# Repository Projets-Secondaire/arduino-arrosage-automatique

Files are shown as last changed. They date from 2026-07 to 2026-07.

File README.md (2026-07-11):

# Arrosage automatique (SI4) – Arduino

Situation d'intégration 4 – Projet de fin d'étude, qualification Électricien-Automaticien
Institut Saint Joseph, Etterbeek – Année académique 2023-2024

## Description

Système d'arrosage automatique pour les plantes de l'atelier, développé sur Arduino UNO. Le système gère à la fois le remplissage d'un réservoir d'eau (depuis un aquarium) et l'irrigation goutte-à-goutte des plantes, avec un sélecteur permettant de basculer entre un mode manuel et un mode automatique piloté par capteurs d'humidité.

## Fonctionnement

**Mode manuel**
- Maintien du bouton de remplissage → la pompe de l'aquarium remplit le réservoir
- Maintien du bouton d'arrosage → la pompe du réservoir démarre et les deux électrovannes s'ouvrent

**Mode automatique**
- Si les deux capteurs d'humidité du sol détectent une sécheresse → la pompe du réservoir démarre et les électrovannes s'ouvrent automatiquement
- Le remplissage du réservoir est régulé par un capteur à ultrason (niveau bas / niveau haut)

**Sécurité**
- Bouton d'arrêt d'urgence (coup de poing) + bouton de reset dédié
- 4 témoins de signalisation : arrosage en cours (vert), niveau bas (jaune), niveau haut (bleu), arrêt d'urgence (rouge clignotant)

## Matériel principal

- Arduino UNO R3
- 2 capteurs d'humidité du sol (hygromètre LM393)
- 1 capteur à ultrason (niveau du réservoir)
- 2 pompes submersibles d'aquarium (JEBAO JECOD)
- 2 électrovannes
- Module 8 relais
- Sélecteur manuel/automatique, boutons poussoir, arrêt d'urgence + reset
- 4 témoins LED de signalisation

La liste complète du matériel (références, caractéristiques techniques, justification des choix) est disponible dans le rapport.

## Firmware

- `firmware/arrosage_automatique/` : programme principal (gestion des deux modes, sécurité, lecture des capteurs)
- `firmware/test_seuil_humidite/` : test isolé du capteur d'humidité du sol, utilisé pour calibrer le seuil avant intégration au programme final

## Rapport complet

Le rapport complet (cahier des charges, étude du système, choix technologiques, dimensionnement, schémas, liste du matériel, grafcet niveau 1/2/3, conclusions et maintenance) est disponible dans [`docs/rapport_arrosage_automatique.pdf`](docs/rapport_arrosage_automatique.pdf).

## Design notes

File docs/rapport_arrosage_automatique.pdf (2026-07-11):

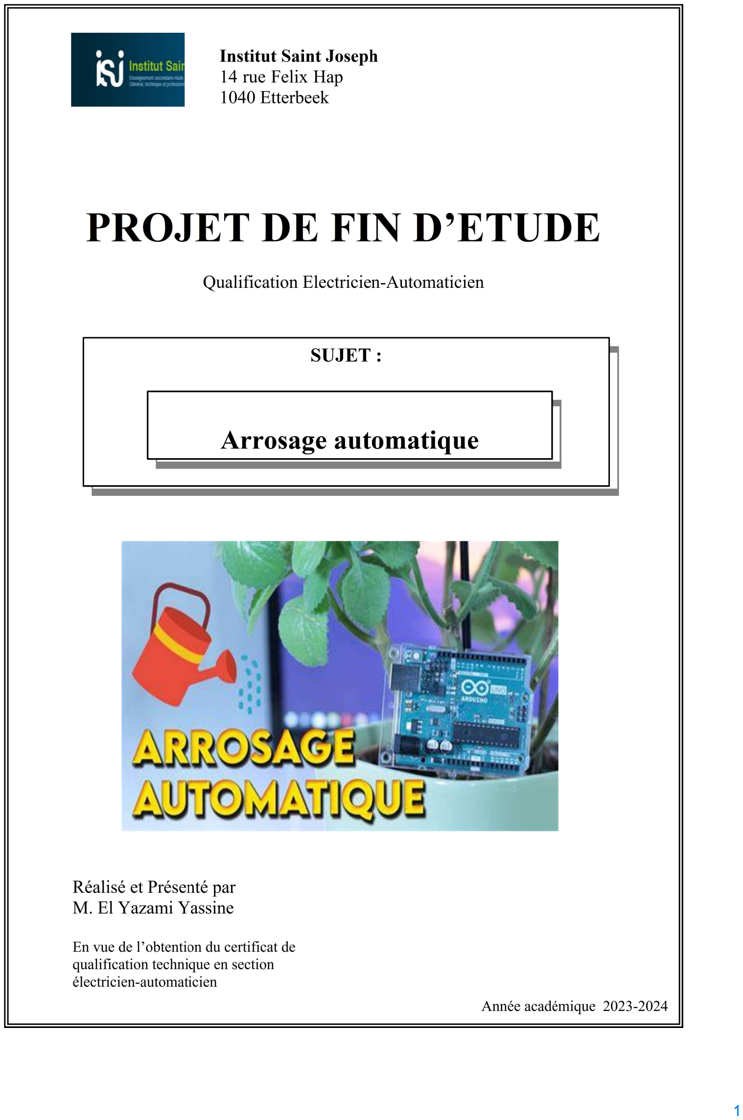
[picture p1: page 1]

## Table des matières

Généralités

But de ce travail de fin d’étude

Ce travail de fin d’étude fait partie de la situation intégrée n°4. Combiné avec trois autres situations intégrées et l'évaluation du stage, permettront d’obtenir le certificat de qualification.
Mes accompagnateurs sont

Monsieur Duliere Bruno qui a joué le rôle de Maître de projet et qui a vérifié le contenu du rapport d’un point de vue technique.
Monsieur Fouad m'a beaucoup aidé avec l'Arduino. Il a pris le temps de m'expliquer comment ça marche et a même corrigé des erreurs dans mon programme. Grâce à lui, j'ai beaucoup mieux compris comment utiliser cette technologie pour mon projet. Madame Bouhamam Kheira m'a aussi apporté une aide précieuse, surtout pour les maths.

Je suis vraiment reconnaissant pour toute l'aide qu'ils m'ont donnée. Ils ont rendu mon travail sur ce projet beaucoup plus facile et agréable

Mes souhait

Dans le cadre du développement de mon projet d'arrosage autonome, mes attentes sont précises et s'articulent autour de la nécessité de maintenir une irrigation efficace et autonome des plantes de l'atelier 200, surtout pendant les périodes où une intervention humaine régulière n'est pas possible.

Le but principal de ce système est de garantir que ces plantes reçoivent la quantité d'eau nécessaire à leur santé et croissance, sans que cela nécessite une intervention manuelle. Cela est particulièrement crucial durant les mois d'été, tels que juillet et août, lorsque les températures élevées peuvent rapidement assécher le sol et où la disponibilité humaine pour l'arrosage peut être limitée.

Je souhaite donc mettre en place un système d'arrosage géré par des capteurs qui détectent l'humidité du sol. Ces capteurs auront pour fonction d'analyser en continu l'état d'humidité et de déclencher un système d'arrosage automatique lorsque le niveau d'humidité descend en dessous d'un seuil prédéfini. Ce mécanisme doit permettre une distribution d'eau homogène et adaptée aux besoins spécifiques de chaque plante.

L'intégration de la technologie Arduino, avec ses capteurs d'humidité du sol, est au cœur de mon projet. Ce choix technologique offre une flexibilité et une précision essentielles pour le contrôle automatisé du système d'arrosage.

En outre, je m'attends à ce que ce système soit économique en eau, contribuant ainsi à une gestion environnementale responsable. Il devrait également être robuste et durable, capable de fonctionner de manière autonome avec un minimum de maintenance.

Mes objectifs

Mon projet d'arrosage autonome représente non seulement une solution pratique pour assurer l'hydratation adéquate des plantes durant les périodes d'absence ou les mois les plus chauds, mais il s'agit également d'une excellente opportunité pour étendre mes compétences techniques et explorer des innovations dans le domaine de l'irrigation.

Approfondissement des compétences techniques: L'utilisation de la plateforme Arduino pour contrôler les capteurs d'humidité du sol et gérer l'irrigation me permettra de parfaire mes connaissances en électronique et en programmation.

Mise en œuvre du système goutte-à-goutte : Un des aspects clés de ce projet est l'intégration d'un système d'irrigation goutte-à-goutte. Ce système permet de distribuer l'eau directement au niveau des racines des plantes à un débit contrôlé, réduisant ainsi le gaspillage d'eau et augmentant l'efficacité de l'arrosage. J'ai utilisé des arroseurs réglables et des capteurs d'humidité sont installés uniquement sur certaines plantes pour détecter la sécheresse. Je régule manuellement l'irrigation en ajustant les petits arroseurs pour chaque plante selon les besoins, en fermant ou en ouvrant complètement à la fin du processus.

Remerciement

Je tiens à exprimer ma profonde gratitude envers Monsieur Duliere Bruno pour son soutien précieux dans ce projet complexe qui a éveillé en moi une véritable passion et le désir de surmonter les défis. Son aide a été cruciale et m'a encouragé à me surpasser.

Je suis également très reconnaissant envers Monsieur Fouad Abdellah, qui m'a énormément appris dans le domaine de l'électronique. Grâce à lui, j'ai pu approfondir mes connaissances en Arduino, ce qui a été essentiel pour la réalisation de mon projet.

Un grand merci à Monsieur L'estrade, dont les idées et les conseils ont été d'une grande aide pour faire avancer mon projet. Sa capacité à fournir des solutions créatives a été d'une grande valeur pour moi.

Enfin, je remercie Madame Bouhaman Kheira pour avoir su éveiller en moi une passion pour les mathématiques. Découvrir ce monde fantastique à travers son enseignement a profondément enrichi mon parcours éducatif.

À vous tous, je suis infiniment reconnaissant pour votre accompagnement, votre patience et votre engagement, qui ont grandement contribué à mon développement personnel et professionnel.

Description du sujet à traiter

Le projet que j’ai développée est conçu pour offrir une flexibilité maximale dans la gestion de l'arrosage, répondant à la fois aux besoins automatiques et manuels d'irrigation. Le système repose sur l’Arduino permettant à l'opérateur de choisir facilement entre deux modes de fonctionnement grâce à un sélecteur dédié.

Modes de Fonctionnement :

### 1. Mode manuel : En positionnant le sélecteur sur le mode manuel et en maintenant le

bouton de remplissage du réservoir enfoncée, le système active la pompe qui se trouve dans l’aquarium pour remplir le réservoir. Cette activation se fait en réponse à l'état du niveau d'eau dans le réservoir ( Bas ou Haut ). Pour arroser manuellement, le sélecteur doit être en mode manuel et en maintenant enfoncée le bouton d’arrosage des plantes. la pompe du réservoir se mettra en marche, les deux électrovannes s’ouvrent pour laisser passer l’eau. Ce mode ne requiert pas l'activation des capteurs d'humidité, donnant ainsi à l'opérateur un contrôle complet sur l'arrosage.

### 2. Mode automatique : L'opérateur peut également choisir de contrôler le système

automatiquement. En plaçant le sélecteur en mode automatique, après cela, si les deux capteur d’humidité sont secs, la pompe du réservoir se met en marche et ouvre les deux électrovannes. Ce mode est idéal pour maintenir un arrosage régulier sans intervention humaine, assurant ainsi que les plantes reçoivent l'eau nécessaire même en l'absence de l'opérateur.

Sécurité et Signalisation :
- Le système est équipé d'un bouton d'arrêt d'urgence ("coup de poing"), permettant une désactivation immédiate en cas de nécessité. Un bouton de reset d’arrêt d’urgence est également présent pour réinitialiser le système après une activation de l'arrêt d'urgence.
- Des témoins lumineux fournissent des informations continues sur l'état du système : i le témoin vert signalent les sessions d'arrosage en cours, le témoin jaune indiquent si le réservoir est vide, le témoin bleu indiquant si le réservoir est rempli et un témoin rouge d'arrêt d'urgence clignote pour alerter l'opérateur en cas d'activation du bouton coup de poing d’arrêt d'urgence.

Etude du système

Choix des technologies

Pour les actionneurs

Pour mon projet d'arrosage automatique, j’ai utilisé quatre témoins, deux électrovannes et deux pompes d'aquarium. Voici la description de chaque actionneur, la justification de ce choix d'un point de vue technique, ainsi que l'énoncé d'autres techniques fonctionnelles possibles.

### 1. Témoins

Technologie retenue : LED témoins

Description : Les LED témoins sont des diodes électroluminescentes qui s'allument pour indiquer l'état de fonctionnement du système. Elles sont utilisées pour signaler le statut de l'arrosage (en cours, terminé) et d'autres états (comme les erreurs ou le niveau d'eau dans le réservoir).

Justification technique :
- Faible consommation d'énergie : Les LED consomment très peu d'énergie, ce qui est idéal pour un système devant fonctionner de manière prolongée.
- Durabilité et fiabilité : Elles ont une longue durée de vie et sont très fiables, minimisant ainsi les besoins de maintenance.
- Visibilité : Les LED offrent une bonne visibilité même en plein jour.

Autres techniques fonctionnelles possibles :
- Afficheurs LCD : Pour fournir plus d'informations, comme des messages de diagnostic ou des statuts détaillés.
- Indicateurs sonores : Pour ajouter des alertes audibles en complément des signaux visuels.

### 2. Électrovannes

Technologie retenue : Électrovannes
Description : Les électrovannes sont utilisées pour contrôler le flux d'eau vers les différentes zones d'arrosage. Elles s'ouvrent et se ferment en réponse à un signal électrique, permettant un contrôle précis de l'irrigation.

Justification technique :
- Contrôle précis : Elles permettent un contrôle précis et rapide de l'ouverture et de la fermeture du flux d'eau.
- Fiabilité : Éprouvées dans des applications industrielles, elles offrent une grande fiabilité et une longue durée de vie.
- Compatibilité : Faciles à intégrer avec des systèmes de contrôle automatisés (microcontrôleurs, automates programmables).

Autres techniques fonctionnelles possibles :
- Vannes mécaniques manuelles : Moins coûteuses mais nécessitent une intervention humaine.

### 3. Pompes d'aquarium

Technologie retenue : Pompes submersibles d'aquarium

Description : Les pompes submersibles sont utilisées pour acheminer l'eau. Elles sont immergées dans l'eau, ce qui permet un fonctionnement silencieux et efficace.

Justification technique :
- Compacité : Leur petite taille permet une intégration facile dans le réservoir d'eau dans l’aquarium.
- Efficacité énergétique: Conçues pour fonctionner de manière continue avec une consommation d'énergie réduite.
- Silencieuses : Idéales pour des environnements où le bruit doit être minimisé.

Autres techniques fonctionnelles possibles :
- Pompes de surface : Peuvent être plus puissantes mais sont souvent plus bruyantes et encombrantes.
- Systèmes de gravité : Utilisation de la gravité pour acheminer l'eau, mais nécessitent un réservoir surélevé.

Conclusion

Les choix des témoins LED, des électrovannes et des pompes submersibles d'aquarium pour ce système d'arrosage automatique ont été guidés par des considérations de fiabilité, d'efficacité énergétique, et de facilité d'intégration.

Pour les pré-actionneurs

Dans ce projet d'arrosage automatique, j’ai intégré plusieurs pré-actionneurs pour garantir un fonctionnement optimal et sécurisé du système. Ces pré-actionneurs comprennent des capteurs d'humidité, des boutons poussoirs, un sélecteur à deux positions, un bouton coup de poing d'arrêt d'urgence, et un capteur à ultrason. Voici la description de chaque pré-actionneur, leur description, ainsi que la justification de nos choix d'un point de vue technique. Nous discuterons également des alternatives possibles pour chaque technologie utilisée.

### 1. Capteurs d'humidité

Technologie retenue : Capteurs d'humidité du sol

Description : Les capteurs d'humidité du sol mesurent le niveau d'humidité dans la terre. Ils sont constitués de deux électrodes insérées dans le sol. Lorsque le sol est humide, l'eau permet une conduction électrique entre les électrodes, ce qui est mesuré et traduit en pourcentage d'humidité.

Justification technique :
- Précision : Ces capteurs fournissent des mesures précises de l'humidité du sol, cruciales pour éviter le sur-arrosage ou le sous-arrosage.

- Facilité d'intégration : Ils sont facilement connectables aux systèmes de microcontrôleurs pour automatiser le déclenchement de l'arrosage.
- Durabilité : Conçus pour résister aux conditions extérieures.

Autres techniques fonctionnelles possibles :
- Capteurs capacitifs d'humidité : Plus résistants à la corrosion, mais souvent plus coûteux.

### 2. Boutons poussoirs

Technologie retenue : Boutons poussoirs

Description : Les boutons poussoirs sont des commutateurs qui ferment ou ouvrent un circuit uniquement lorsque le bouton est pressé. Ils sont utilisés pour les commandes manuelles dans le système d'arrosage.

Justification technique :
- Simplicité : Faciles à utiliser et à installer, offrant un contrôle direct.
- Fiabilité : Longue durée de vie et résistance à l'usure.
- Coût : Relativement peu coûteux.
Autres techniques fonctionnelles possibles :
- Interrupteurs à bascule : Fournissent une alternative pour des états maintenus.
- Capteurs tactiles : Offrent une interface plus moderne et sans usure mécanique.

### 3. Sélecteur à deux positions

Technologie retenue : Sélecteur à deux positions (bascule)

Description : Le sélecteur à deux positions permet de basculer entre deux états, comme "manuel" et "automatique". Il s'agit d'un interrupteur à deux positions fixes.

Justification technique :
- Clarté: Indique clairement l'état du système.
- Facilité d'utilisation: Permet un changement rapide et sûr entre les modes de fonctionnement.
- Robustesse : Conçu pour une utilisation fréquente.

Autres techniques fonctionnelles possibles :
- Sélecteurs rotatifs : Offrent plusieurs positions et peuvent inclure des options supplémentaires.
- Interrupteurs à clé : Ajoutent un niveau de sécurité en permettant uniquement aux utilisateurs autorisés de changer les modes.

### 4. Bouton coup de poing d'arrêt d'urgence

Technologie retenue : Bouton coup de poing d'arrêt d'urgence

Description : Le bouton coup de poing est un interrupteur de sécurité utilisé pour arrêter immédiatement le système en cas d'urgence. Il est conçu pour être facilement accessible et activé rapidement en appuyant fortement.

Justification technique :
-Sécurité : Fournit une méthode rapide et visible pour arrêter le système en cas de problème.
- Fiabilité : Construit pour une activation rapide et fréquente sans défaillance. Autres techniques fonctionnelles possibles :
- Arrêts d'urgence sans contact : Utilisation de capteurs pour détecter des gestes ou des interruptions de faisceaux laser.

### 5. Capteur à ultrason

Technologie retenue : Capteur à ultrason

Description : Le capteur à ultrason mesure la distance entre le capteur et un objet en émettant des ondes sonores et en mesurant le temps de retour de l'écho. Dans le contexte de l'arrosage automatique, il peut être utilisé pour mesurer le niveau d'eau dans un réservoir.

Justification technique :
- Précision : Fournit des mesures précises de distance sans contact physique avec l'eau.
- Fiabilité : Moins sujet aux erreurs causées par la saleté ou les débris par rapport à d'autres capteurs de niveau.
- Facilité d'installation : Peut être monté au-dessus du réservoir sans modifications importantes.

Autres techniques fonctionnelles possibles :
- Capteurs de niveau à flotteur : Simples et fiables mais nécessitent un contact direct avec l'eau.
- Capteurs capacitifs de niveau : Offrent une alternative sans contact mais peuvent être plus coûteux.
Conclusion

Les technologies retenues pour les pré-actionneurs de ce système d'arrosage automatique ont été choisies pour leur précision, leur fiabilité et leur facilité d'intégration. Chaque choix a été justifié par des considérations techniques spécifiques, bien que des alternatives fonctionnelles existent et pourraient être envisagées selon les besoins et les contraintes du projet.

Dimensionnement(s)

Calcul du volume d’eau dans l’aquarium :

V = L.l.H | 1 dm³ = 1 litre

Dimension de l’aquarium : L = 131 cm l = 38,5 cm H = 47 cm

V aquarium = 131 . 38 ,5 . 47 = 237044, 5 cm³/ 1000 = 237, 0445 litres

l’aquarium sera vidé de 1 /3 pour éviter de nuire aux poissons donc :

237,0445 . 1/3 = 79,015 litres

Pompe Aquarium : 3200 L/H 3200/3600 = 8/9 L/S 79,015/8/9 = 88,89 sec = 1 min 28 sec 89ms

V réservoir = 80 . 30 . 35 = 84000 cm³ /1000 = 84 Litres

Note de calcul de l’alimentation : U = 24 VDC | I = 20 A
P = U . I | P = 24 . 20 = 480 W

H1 = H2 = H3 = H4 = 25 W . 4 = 100 W

PA = 25 W PR = 12 W

EV1 = EV2 = 6 W . 2 = 12 W

Ptotal = 100 + 25 + 12 + 12 = 149 W

Par conséquent l’alimentation est conforme à cette conception .

Problèmes rencontrés et solutions apportées.

J'ai rencontré un problème avec Arduino où je ne parvenais pas à lui faire comprendre que lorsqu'un bouton est enfoncé, il devait effectuer une action spécifique. Pour gérer les boutons, j'ai trouvé une solution : définir en état haut les éléments en circuit fermé comme le bouton d'arrêt d'urgence ou les sélecteurs, tandis que pour les boutons poussoirs, je les ai définis en état bas, car ils nécessitent d'être enfoncés pour envoyer le signal.

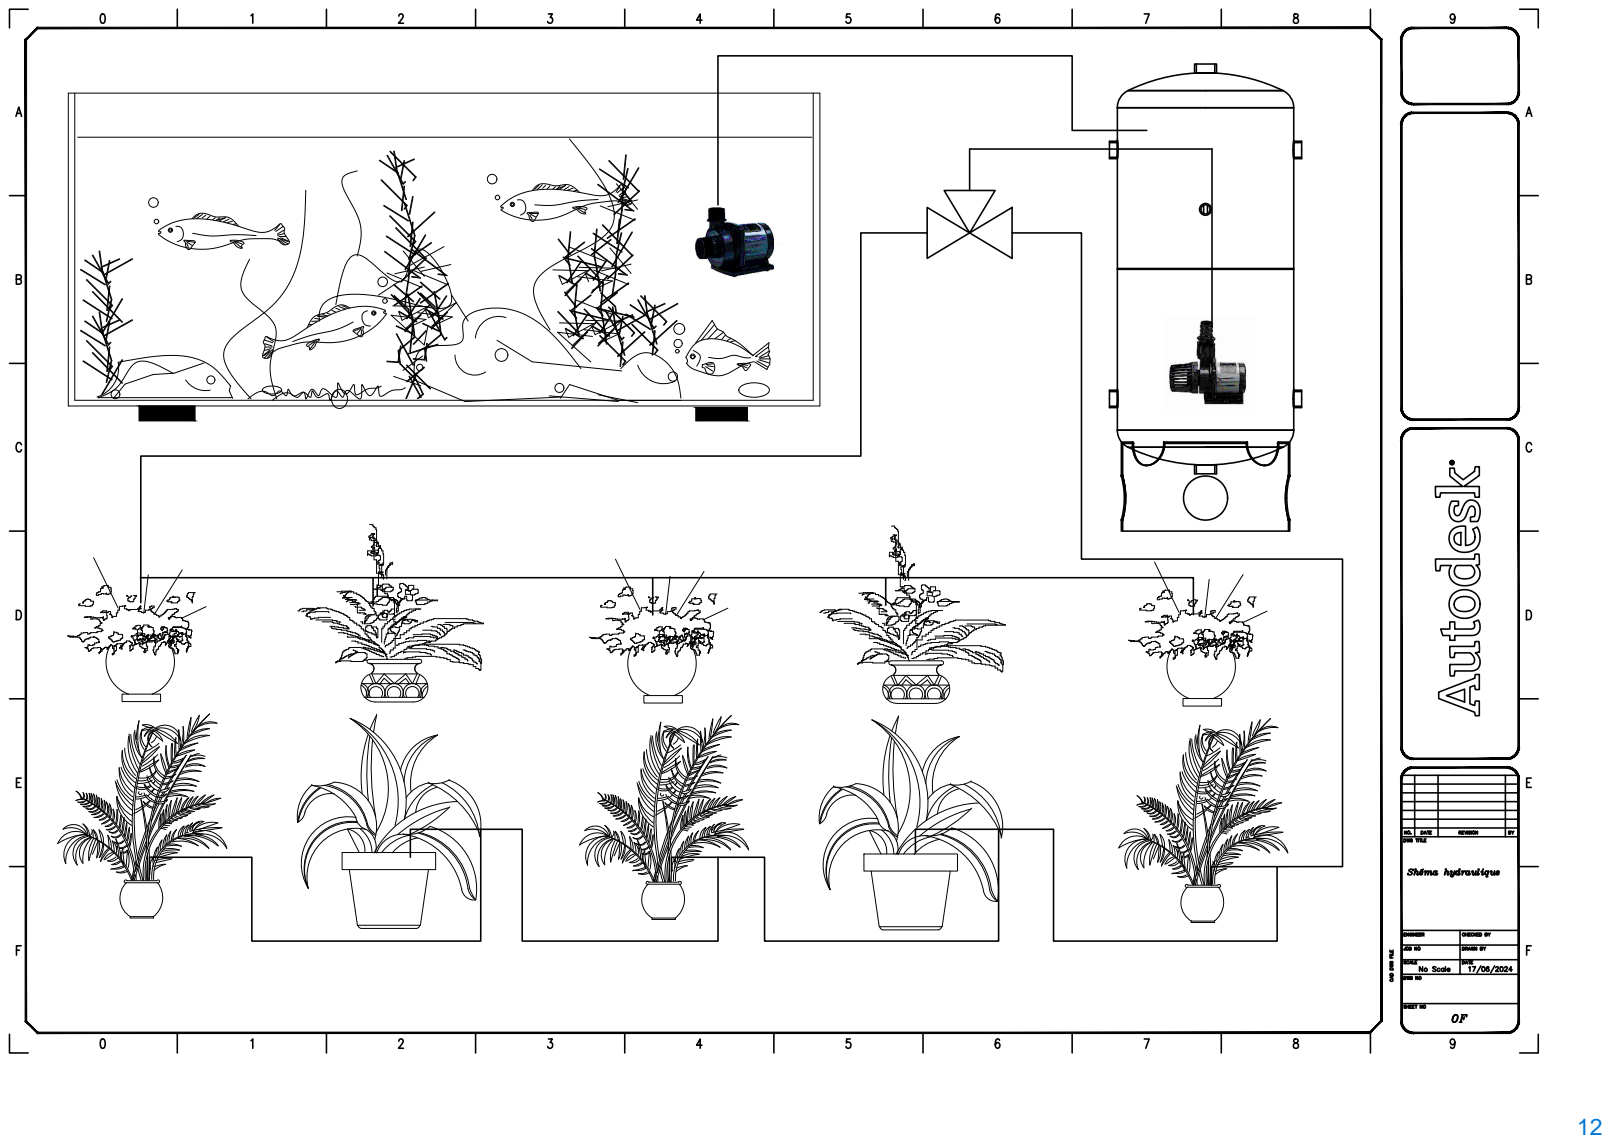
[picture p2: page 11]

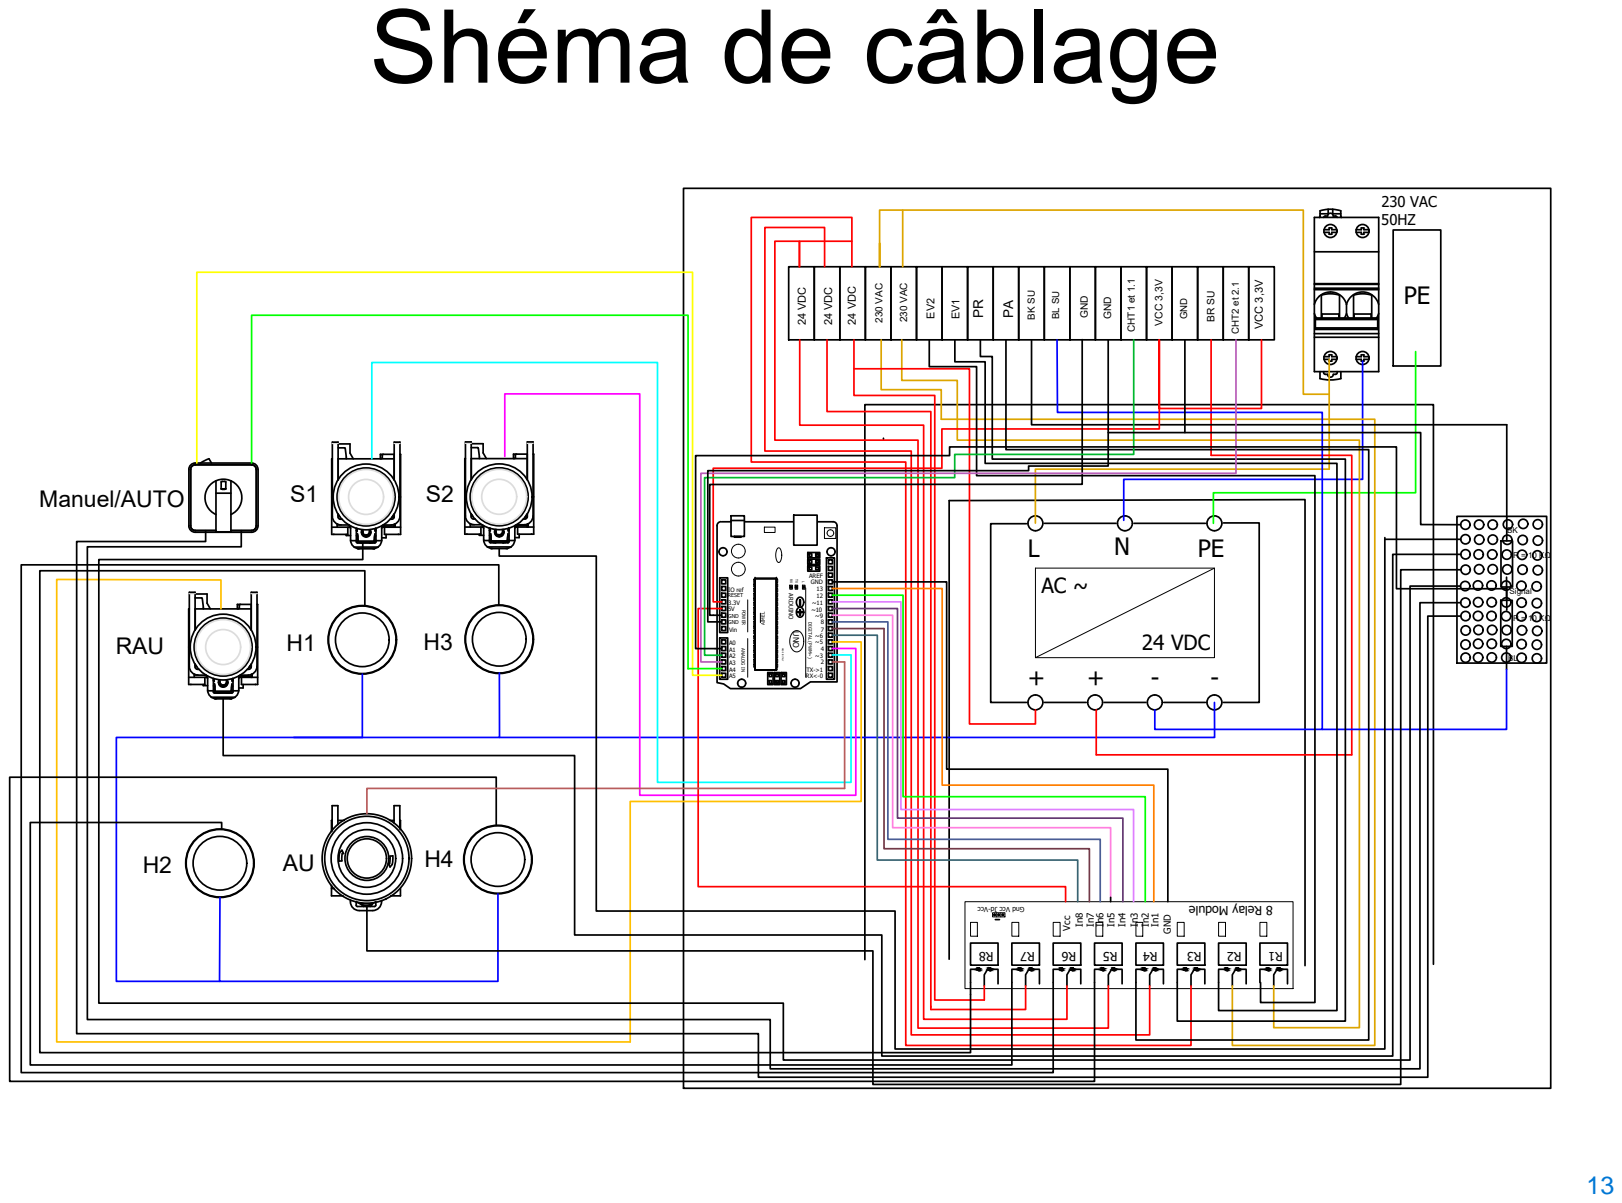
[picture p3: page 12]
Vcc; In1 R8 8 Relay Module; ARDUINO; TX UNO; AIMEL; 24 VDC; GND; CHT1 et 1.1

230 VAC Shéma de câblage

BR SU R = 10 KΩ R = 10 KΩ Signal BKBL 230 VAC 50HZ

230 VAC H2 H1 H3H4 RAU S1 S2 AU Manuel/AUTO

MADE IN ITALY AC ~ - - L 24 VDC + N PE + PE

BL SU GND

VCC 3,3V VCC 3,3V GND CHT2 et 2.1

POWER ANALOG IN RESET 5VIO ref RXL A5A4A3A0A2A1 ~912 ~10 TX->1 RX<-0 ~11847 ~32 13

DIGITAL (PWM~) ~5 ~6 AREF GND

GND R1 3.3V GND GND Vin

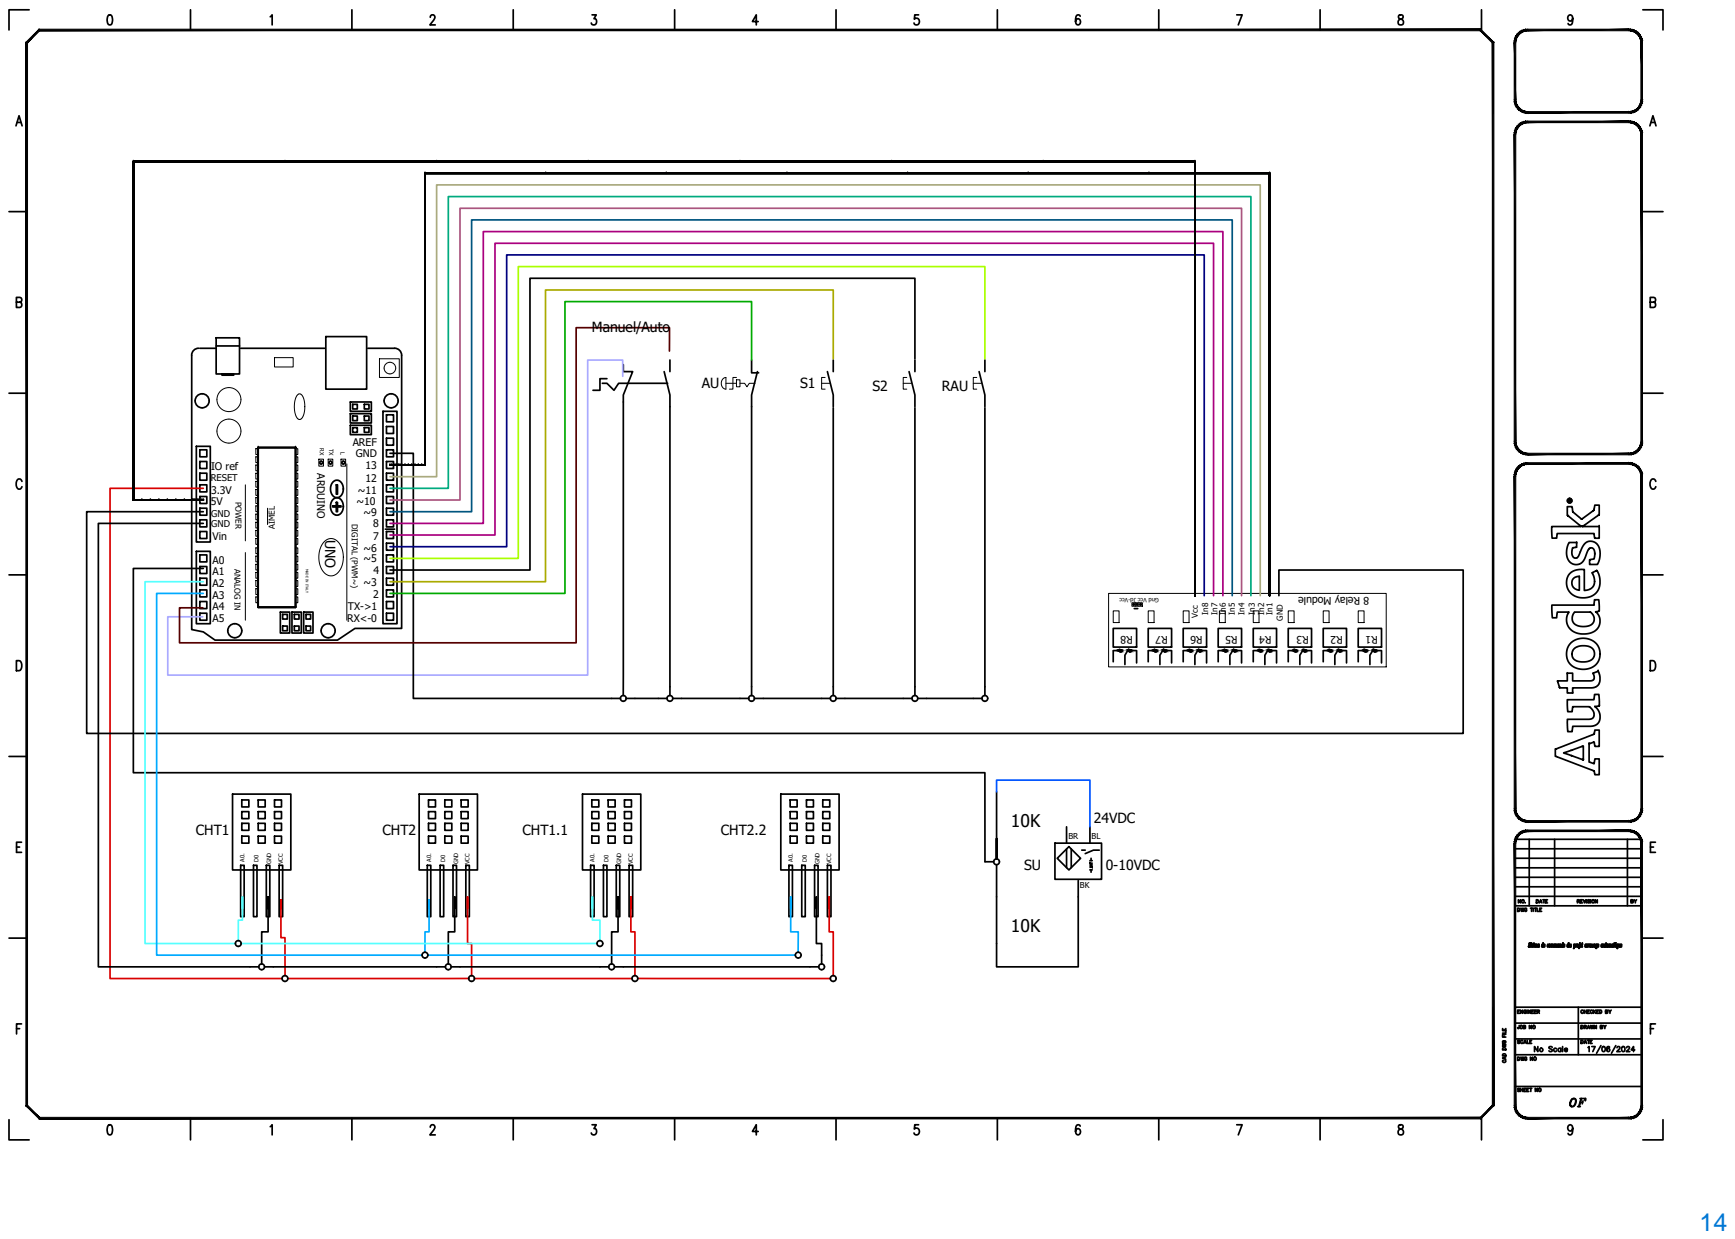
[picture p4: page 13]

VCC BR BK BL 10K 0-10VDC 10K CHT1 S2 CHT2 Manuel/Auto 24VDC RAU

POWER ANALOG IN RESET 5VIO ref RXL A5A4A3A0A2A1 ~912 ~10 TX->1 RX<-0 ~11847 ~32 13

DIGITAL (PWM~) ~5 ~6 AREF GND

GND R1 3.3V GND GND Vin

MADE IN ITALY A0. D0 GND

VCC Gnd Vcc Jd-Vcc R7 R6 R5 R4 R3 R2

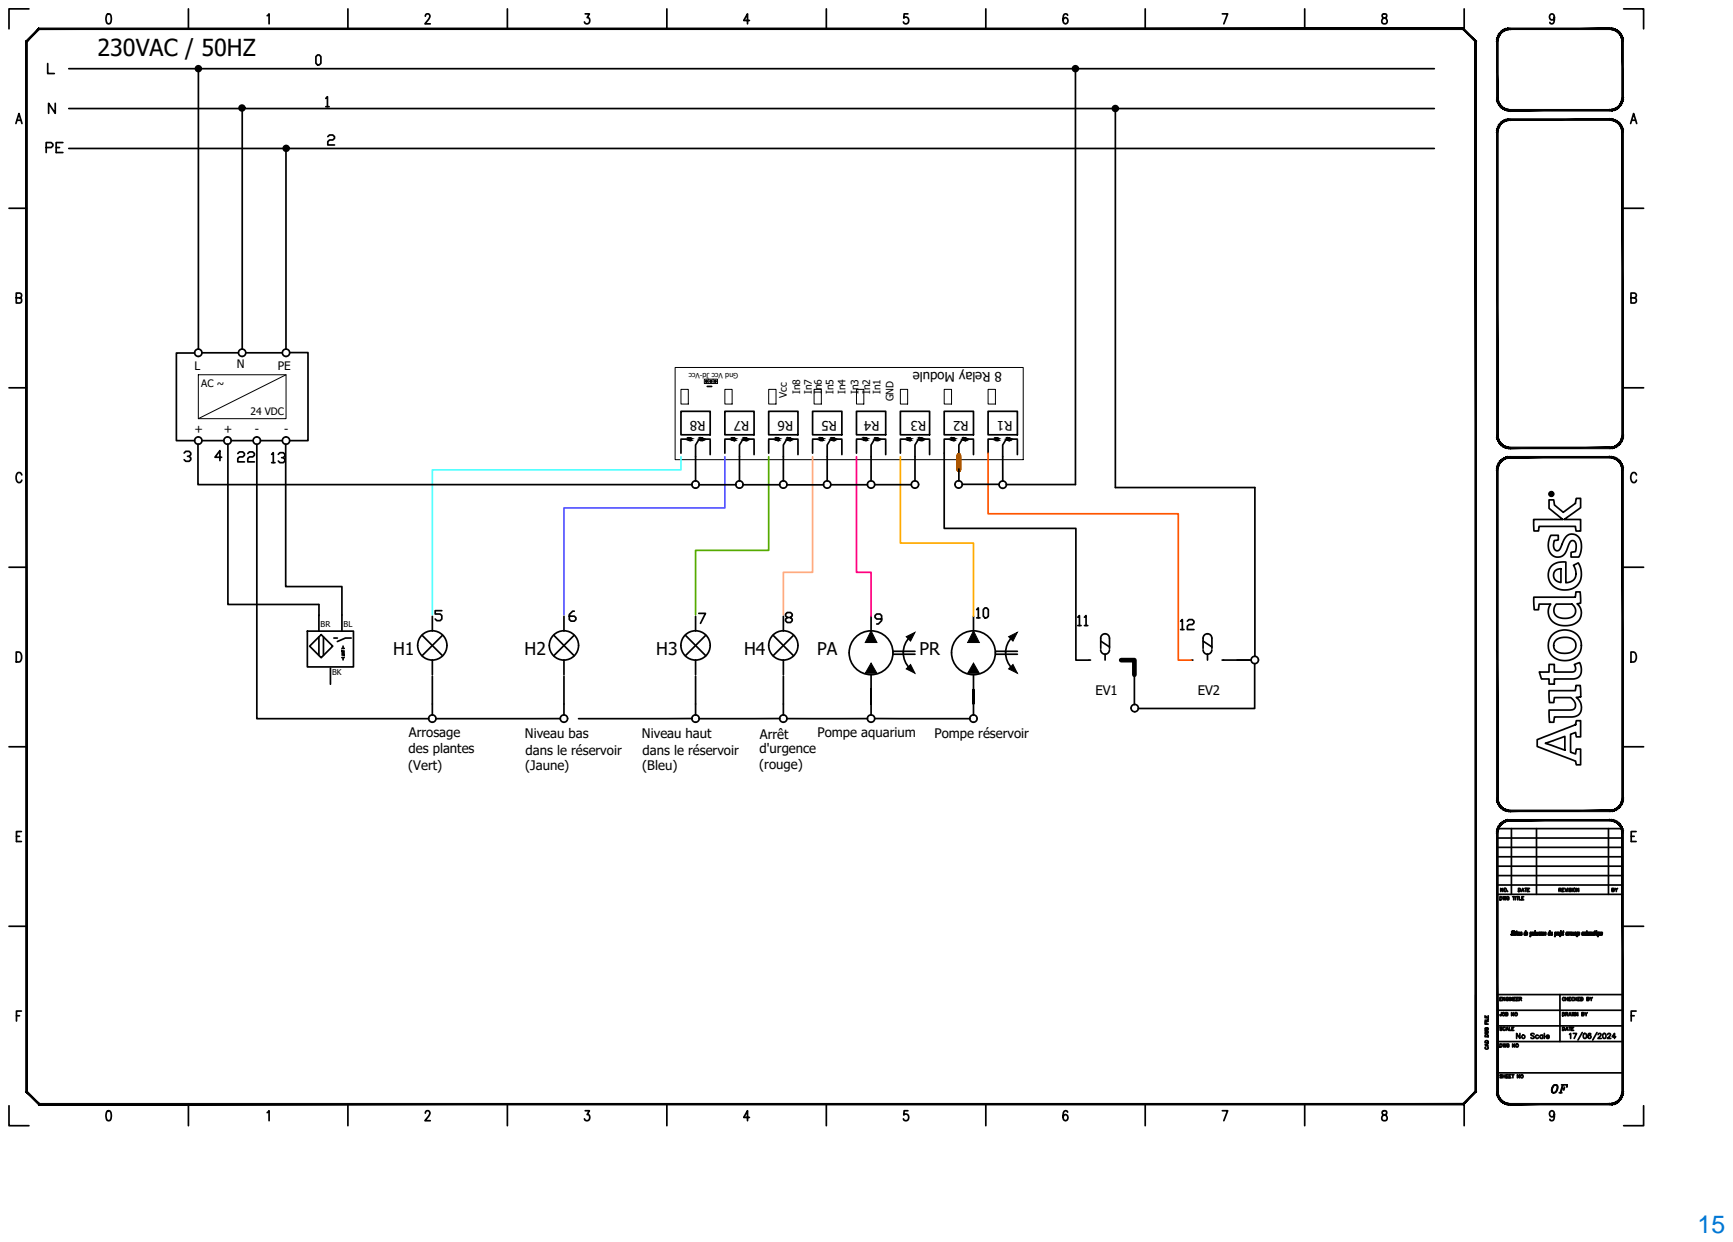
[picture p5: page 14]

GND R1 H1 H2 H3 H4 PA PR Niveau haut dans le réservoir (Bleu) Arrosage Pompe réservoir des plantes (Vert) Arrêt d'urgence (rouge) Pompe aquarium EV1 EV2 Niveau bas dans le réservoir (Jaune) 230VAC / 50HZ BR BK BL

Liste du matériel pour le projet d’arrosage automatique

Nom du composant | Description du composant | Caractéristique | La marque | La référence
Arduino UNO | La carte Arduino Uno R3 est un microcontrôleur compact qui offre une excellente introduction aux systèmes embarqués et à la programmation. | Tension de fonctionnement : 5V. Tension d’alimentation recommandée : 7-12V. Broches E/S numériques : 14 (dont 6 disposent d’une sortie PWM Broches d’entrées analogiques : 6 Intensité maximale disponible pour la sortie 5V : 500 mA max | Arduino | ARDUINO-UNO-R3
Pompe submersible | Cette pompe est conçue pour être utilisée dans des aquariums et offre plusieurs caractéristiques avantageuses pour maintenir un environnement aquatique stable et sain. | Débit réglable : de 400 à 1200 l/h. Consommation d’énergie : 12 Watts. Sécurité : La pompe est dotée d’un arrêt d’urgence en cas de fonctionnement à sec. Tension de fonctionnement : 24V basse tension. | JEBAO JECOD | DCS-1200
Pompe submersible | Cette pompe est conçue pour être économique en énergie et convient pour une utilisation en eau douce ou en eau de mer. La pompe est également équipée d’un mode d’alimentation en un clic qui arrête la pompe pendant 10 minutes. | Débit réglable : de 900 à 3000 litres par heure. Consommation d’énergie : 25 Watts. Tension de fonctionnement : 24V basse tension. | JEBAO JECOD | DCS-3000

Capteur
d’humidité

Ce capteur est
équipé d’un stylet à
deux électrodes
agit comme une
résistance variable
dont la valeur
change en fonction
de la teneur en eau
du sol. Plus il y’a
d’eau dans le sol,
meilleure est la
conductivité et la
résistance est plus
faible. Inversement
moins il y a d’eau,
moins la
conductivité est
importante et plus
la résistance du sol
est élevée.

Alimentation : le
capteur
fonctionne avec
une alimentation
de 3,3 à 5 V.
Sorties : le
capteur dispose
des sorties
numérique et
analogiques.
Consommation
de courant :
faible courant
(35mA).
Arduino | Hygromètre LM393
Module 8 relais Arduino | Ce module relais est idéale pour contrôler des charges lourdes ou des appareils fonctionnant à des élevées. Son avantage est qu’il peut être piloté par un Arduino ou d’autre microcontrôleur. | Tension de fonctionnement : 5V. Type de relais : il s’agit d’un relais électromécanique. Courant de charge nominal : le module peut gérer un courant de charge jusqu’à 10 A. Tension de commutation : il peut commuter des charges jusqu’ | Arduino | Open 436
Stripboard | Il s’agit d’une carte de prototypage au format Eurocard, fabriquée en papier époxy. Elle est pré-percée. | Diamètre des trous : 1 mm Épaisseur de la carte : 1,6 mm Longueur de la carte : 160 mm Largeur de la carte : 100 mm | Gspk circuits | 451058
Capteur à ultrason | Ce capteur est conçu pour des applications industrielles où la détection précise d’objets est nécessaire, même dans des conditions difficiles. Sa portée | Portée nominale : 0,5 m, réglable avec un bouton d’apprentissage à distance. Sortie : 0...10V Tension d’alimentation : 12 à 24 VDC | Telemecanique | XX918A3F1M12

| réglable et sa sortie analogique le rendent flexible pour diverses utilisations. | Distance de détection : De 50 à 500 mm.
Alimentation monophasée | Il s’agit d’une alimentation pour rails DIN 24 V DC/20 A, à découpage primaire, monophasée | Tension d’entrée : 100 V AC … 240 V AC ou 90 V DC … 350 V DC1. Courant nominal de sortie : 20 A (jusqu’à 60 °C) avec POWER BOOST jusqu’à 26. Rendement : > 92 %. Tension de sortie nominale : 24 V DC. Plage de réglage de la tension de sortie : 22,5 V DC … 28,5 V DC | Phoenix Contact | 2938620
Disjoncteur monophasé | C'est un appareil de protection électrique utilisé pour couper automatiquement le circuit en cas de surcharge ou de court-circuit. | Type : disjoncteur bipolaire. Courant nominal : 4A. Tension : 230 VAC Pouvoir de coupure : 6000 A (10KA) | Legrand | 407779
Électrovanne 4 voies | Électrovanne 4 voies pour lave-linges. | Contrôle l’arrivée d’eau dans différents compartiments de la machine, alimentation 230 VAC. Résistance à l’eau et l'usure | Thomson, Brandt, Vedette | 030825

Tableau d’affectation des entrées et sorties pour le projet d’arrosage automatique (Arduino)

Entrées
SM : Sélecteur mode manuel | A5
SA : Sélecteur mode arrosage automatique | A4
AU : bouton coup de poing d’arrêt d’urgence | 2
S1 : Bouton poussoir mode manuel arrosage | 3
S2 : Bouton poussoir remplissage de la cuve | 4
RAU : reset d’arrêt d’urgence | 5
CHT 1 | A2
CHT 2 | A3
CHT 1.1 | A2
CHT 2.1 | A3
SU | A1
Sorties
EV2 : électrovanne 2 pour le capteur d’humidité 2 | 13
EV1 : électrovanne 1 pour le capteur d’humidité 1 | 12
PR : pompe du réservoir | 11
PA : pompe de l’aquarium | 10
H4 : témoin rouge indiquant l’arrêt d’urgence | 9
H3 : témoin bleu indiquant que le niveau dans le réservoir est haut | 8
H2 : témoin jaune indiquant que le niveau dans le réservoir est bas | 7
H1 : témoin vert indiquant que l’arrosage est en cours | 6

Si le selecteur est en mode automatique et que le capteur à ultrason détecte une distance de 50 cm ? Le témoin H2 s'allume pour indiqué que le niveau d'eau dans le réservoir est bas ! | La pompe du réservoir s'arrête et l'électrovanne 1 et 2 se désalimentent et le témoin vert s'éteint ! La pompe de l'aquarium se met en marche pour remplir le réservoir ! | Le capteur a ultrason detecte une distance de 6 cm ? Le témoin d'arrêt d'urgence clignote pour avertir l'opérateur que la machine est en panne, la pompe d'aquarium et La pompe du réservoir n'est plus sous tension, l'électrovanne 1 et l'électrovanne 2 ne sont plus sous tension le témoin vert s'éteint ! | 1 | Si le selecteur est en mode manuel et que l'opérateur maintien enfoncée le bouton de remplissage du réservoir et que le capteur a ultrason détecte une distance de 50 cm ? Le témoin bleu s'allume signalant que le réservoir est plein, le témoin jaune s'éteint La pompe du réservoir se met en marche, l'électrovanne 1 et l'électrovanne 2 laisse passer l'eau et le témoin vert s'allume indiquant l'arrosage des plantes ! MANUEL 10 | Si le selecteur est en mode automatique et que le capteur a ultrason detecte une distance de 6 cm ? Si les capteurs d'humidités 1 et les capteurs d'humidité 2 detectent une secheresse ? | 0 22 2 | 11 AUTOMATIQUE | La pompe du réservoir se met a fonctionner, l'électrovanne 1 et 2 laisse passer l'eau et le témoin vert s'allume indiquant l'arrosage des plantes ! | Si le selecteur est en mode manuel et que l'opérateur maintien enfoncée le bouton mode arrosage et que si Le capteur a ultrason detecte une distance de 6 cm ? Arrêt d'urgence remis en position de départ et une impulsion sur le bouton de reset d'arrêt d'urgence ? | Le témoin bleu s'allume siganalant que le réservoir est plein donc l'arrosage pourrait être effectuer ! | La pompe du réservoir s'arrête ou la pompe d'aquarium s'arrête, l'électrovanne 1, ainsi l'électrovanne 2 se désaliment et le témoin vert s'éteint ! Arrêt d'urgence ? | Le témoin bleu s'allume signalant que le réservoir est plein, La pompe du réservoir se met en marche, l'électrovanne 1 et l'électrovanne 2 laisse passer l'eau et le témoin vert s'allume indiquant l'arrosage des plantes ! Si le selecteur n'est pas en mode manuel ou que l'opérateur relache le bouton mode remplissage ou le bouton manuel arrosage des plantes ? Le témoin H2 s'allume pour indiqué le niveau d'eau dans le résevoir est bas, La pompe de l'aquarium se met en marche pour remplir le reservoir ! Si le selecteur est en mode manuel et que l'opérateur maintien le bouton de remplissage du réservoir ? | le capteur à ultrason détecte une distance de 50 cm ? le capteur à ultrason détecte une distance de 6 cm ? Le témoin H2 s'allume pour indiqué que le niveau d'eau dans le réservoir est bas ! | Le témoin H3 s'allume pour indiqué que le niveau d'eau dans le réservoir est haut ! 1413 | 15 le capteur à ultrason détecte une distance de 6 cm ? La pompe de l'aquarium s'arrête et le témoin bleu s'allume ! | 56 Si les capteurs d'humidités 1 et les capteurs d'humidité 2 estime que le sol est sufissament humide ? 34 | 16

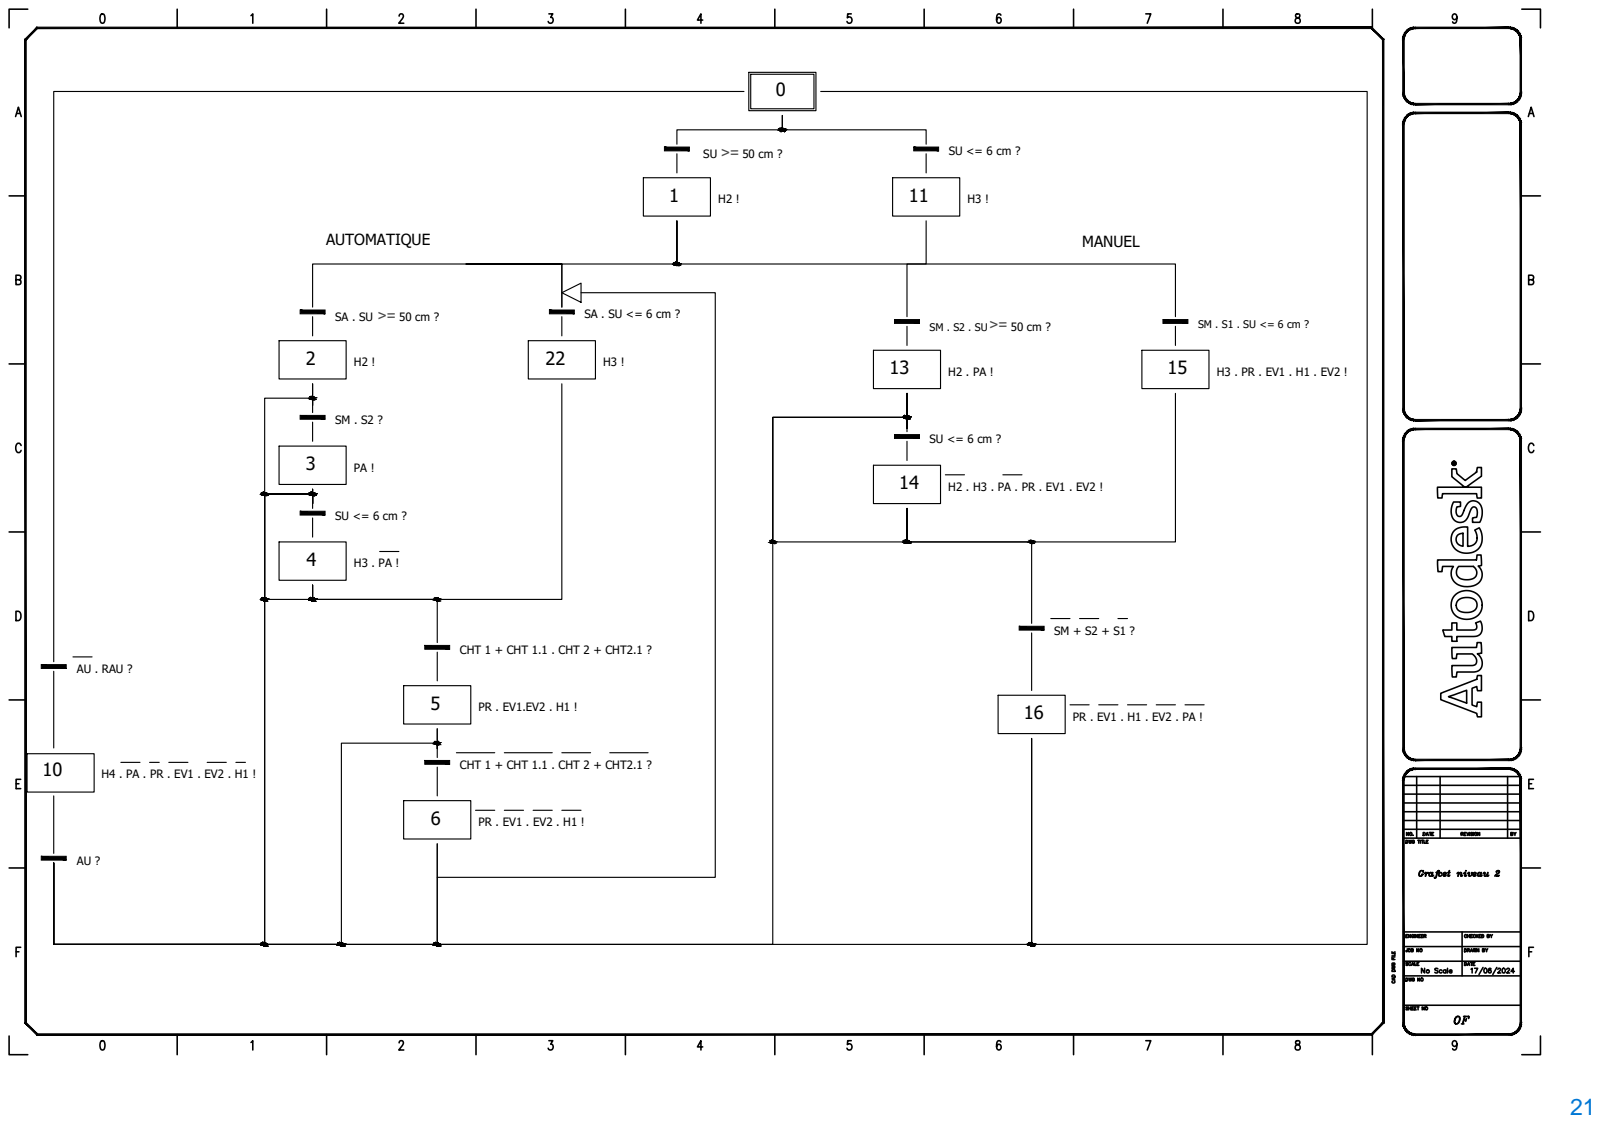
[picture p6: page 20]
14 PA ! AU . RAU ?; SM + S2 + S1 ? PR . EV1 . H1 . EV2 . PA ! MANUEL 2; PR . EV1.EV2 . H1 ! CHT 1 + CHT 1.1 . CHT 2 + CHT2.1 ? H3 . PA ! SU <= 6 cm ? H4 . PA . PR . EV1 . EV2 . H1 !; CHT 1 + CHT 1.1 . CHT 2 + CHT2.1 ? 4; SM . S1 . SU <= 6 cm ? AUTOMATIQUE SA . SU >= 50 cm ? H2 !

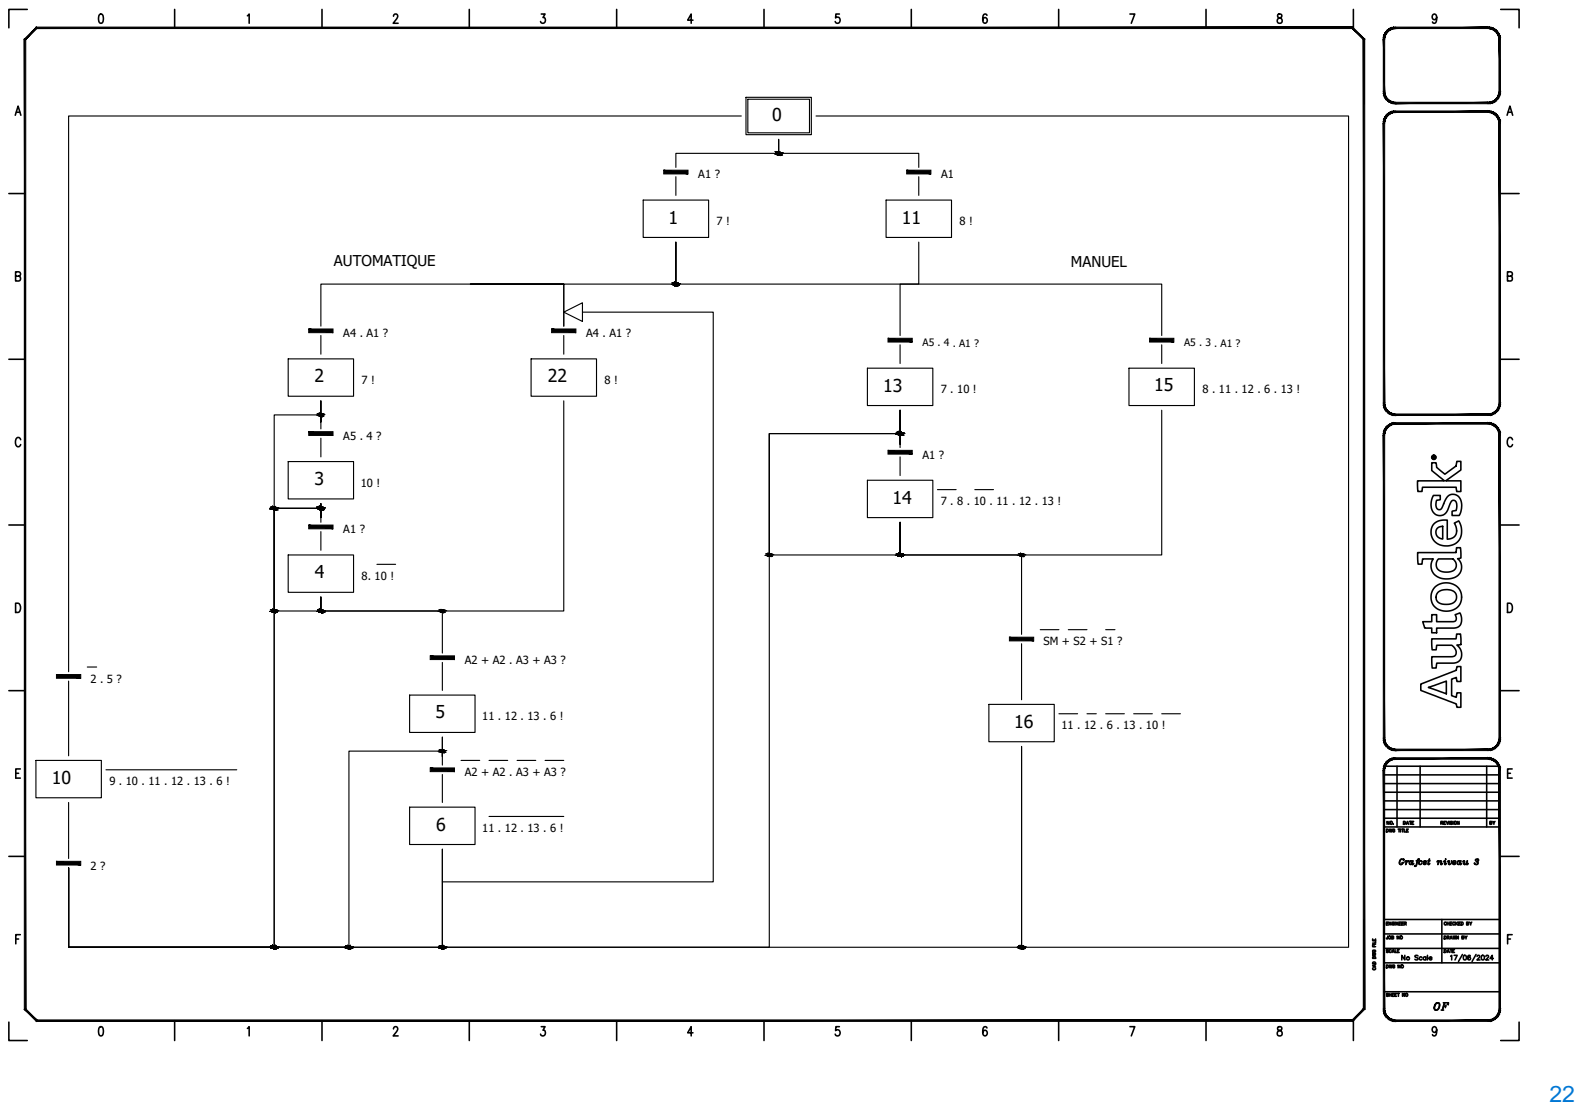
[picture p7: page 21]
7 ! AUTOMATIQUE A4 . A1 ?; 11 . 12 . 6 . 13 . 10 ! MANUEL 8 !

Conclusion

Les remarques et améliorations éventuelles.

Pour le premier choix technologique, j'ai opté pour le capteur à ultrasons pour éviter tout débordement dans le réservoir et surveiller le niveau d'eau avec des témoins lumineux. Cependant, pour l'aquarium, j'ai préféré économiser en calculant le volume plutôt que d'utiliser un capteur à ultrasons. Pour le deuxième choix, j'ai automatisé l'arrosage avec des capteurs d'humidité offrant un contrôle précis, plutôt qu'un module RTC, permettant de réguler la fréquence d'arrosage une fois par semaine ou deux.

Mon apprentissage personnel.

Oui, mes souhaits et objectifs ont été vérifiés par rapport à l'énoncé de départ. Mon projet d'arrosage autonome pour l'atelier 200 visait à maintenir une irrigation efficace sans intervention humaine constante, surtout en été. J'ai mis en place un système d'arrosage automatisé utilisant des capteurs d'humidité du sol et la technologie Arduino, permettant une distribution d'eau adaptée aux besoins des plantes. Ce projet m'a également permis de développer mes compétences techniques en électronique et programmation. Les résultats ont été conformes à mes attentes initiales.

Etude des trois niveaux de maintenance apportés au projet

Pour assurer la fiabilité et l'efficacité du système d'arrosage automatique, il est essentiel de mettre en place un plan de maintenance structuré. Voici une étude des trois niveaux de maintenance pour ce projet :

### 1. Maintenance Préventive

Objectif : Prévenir les pannes et optimiser la durée de vie des composants.

Actions :
- Inspection régulière : Vérification périodique des tuyaux, raccords, électrovannes, et goutteurs pour détecter toute usure ou fuite.
- Vérification des capteurs : Contrôler régulièrement les capteurs d'humidité pour s'assurer qu'ils fonctionnent correctement.

### 2. Maintenance Corrective

Objectif : Réparer les pannes et dysfonctionnements dès qu'ils surviennent pour minimiser les interruptions de service.

Actions :
- Réparation des fuites : Intervenir rapidement pour réparer ou remplacer les tuyaux et raccords en cas de fuite détectée.

- Remplacement des composants défectueux : Remplacer immédiatement les capteurs d'humidité, électrovannes, ou tout autre composant défaillant pour restaurer le bon fonctionnement du système.
-Ajustement des arroseurs : Si un arroseur ne fonctionne pas correctement, le réajuster ou le remplacer pour garantir une distribution uniforme de l'eau.

### 3. Maintenance Améliorative

Objectif : Améliorer le système existant pour augmenter son efficacité et sa performance.
Actions :
- Amélioration des capteurs : Remplacer les capteurs d'humidité par des modèles plus précis ou plus robustes pour améliorer la fiabilité du système.
Conclusion

En mettant en place ces trois niveaux de maintenance, le projet d'arrosage automatique sera bien équipé pour fonctionner de manière fiable et efficace, avec une réduction des pannes, une optimisation des performances, et une prolongation de la durée de vie des composants.

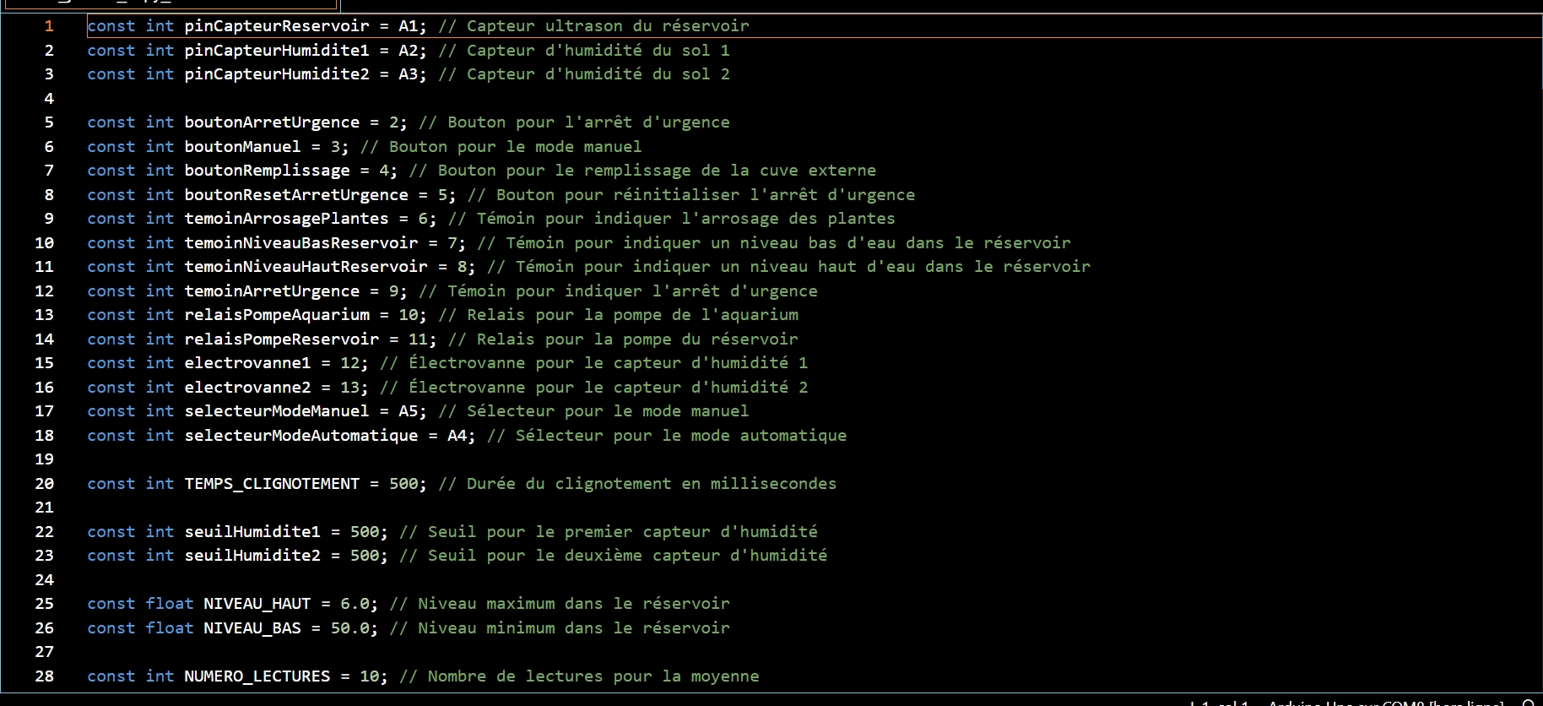
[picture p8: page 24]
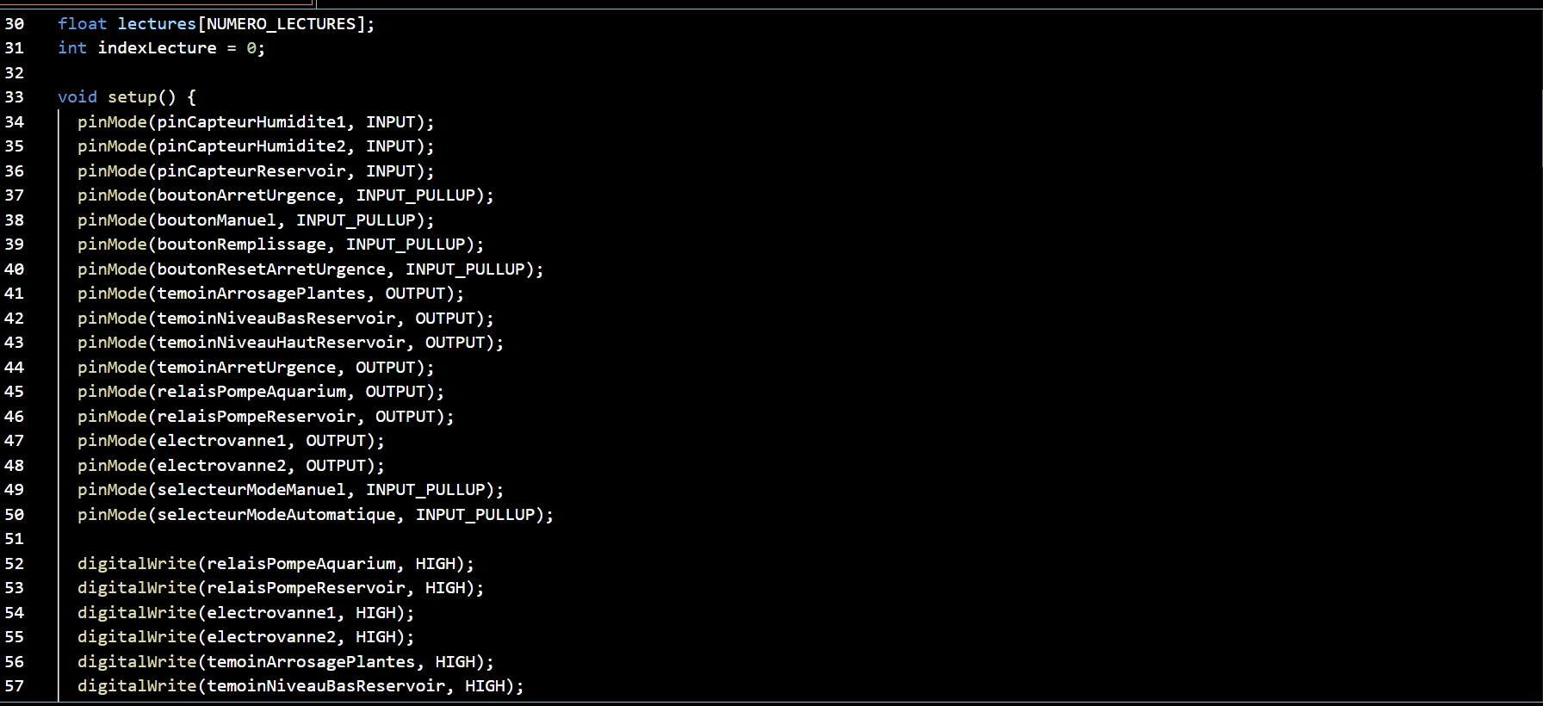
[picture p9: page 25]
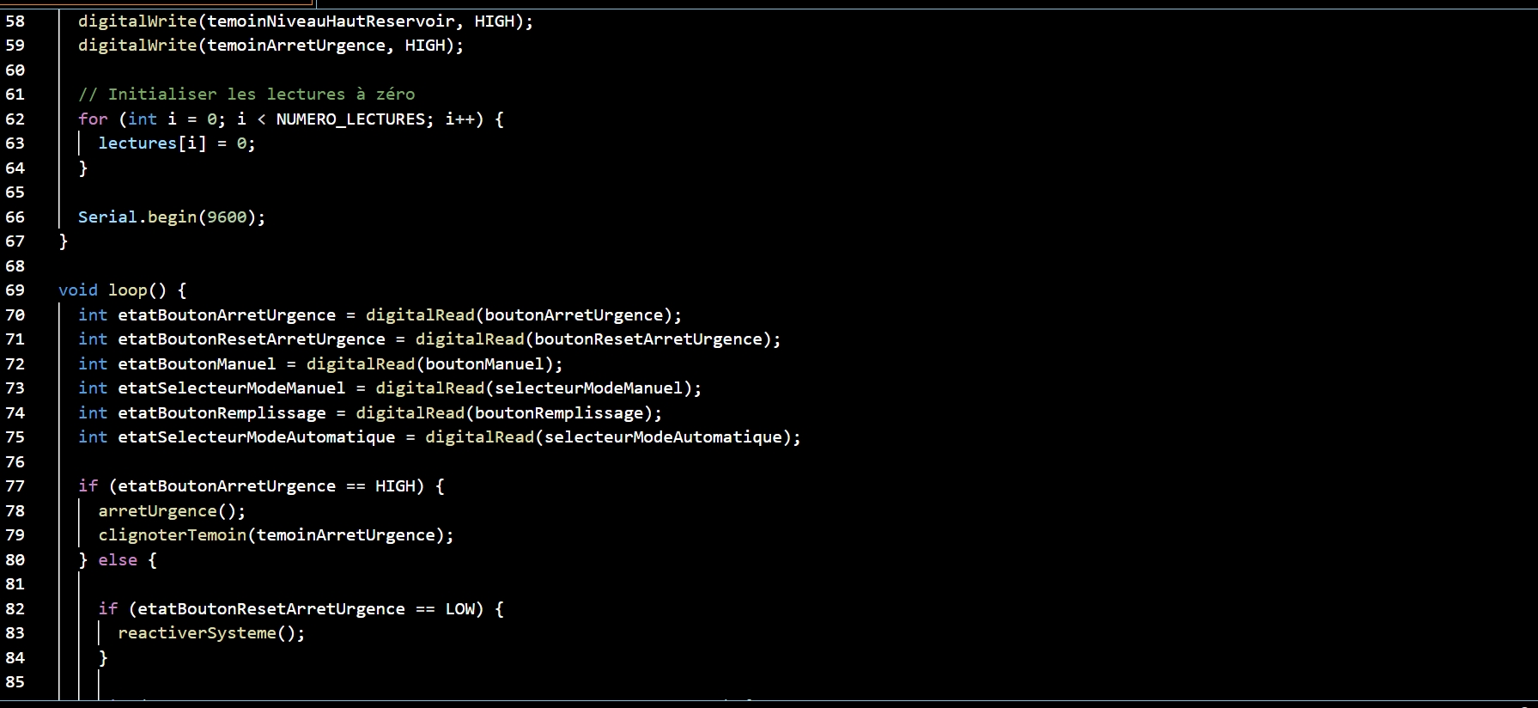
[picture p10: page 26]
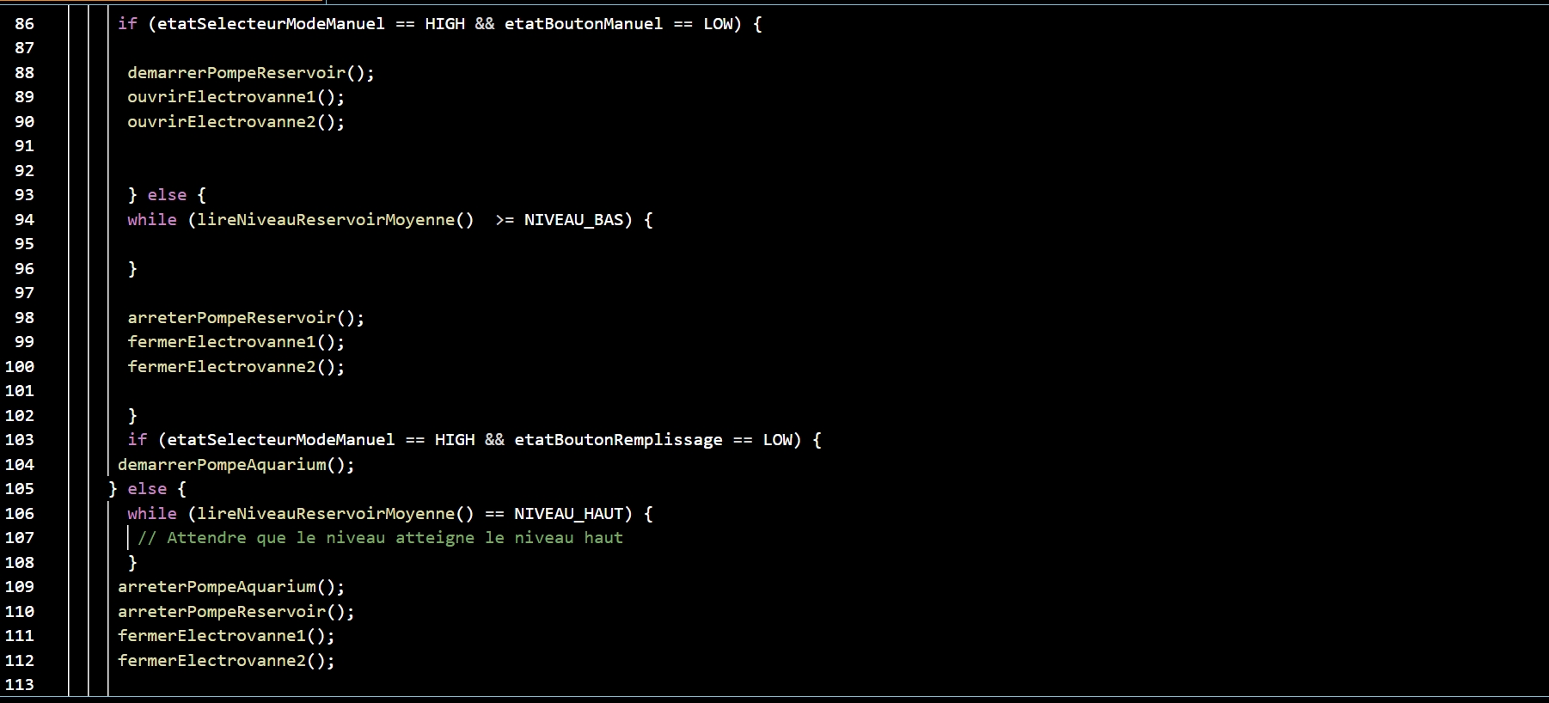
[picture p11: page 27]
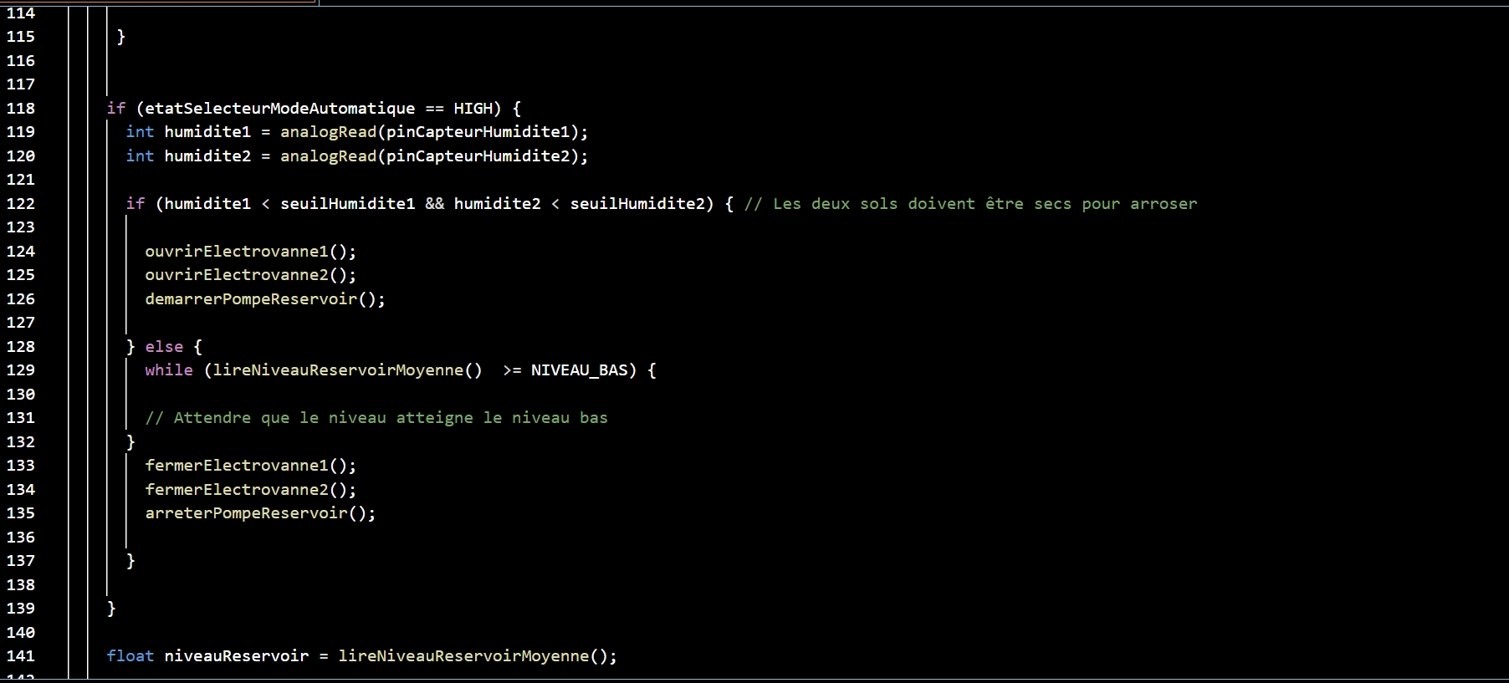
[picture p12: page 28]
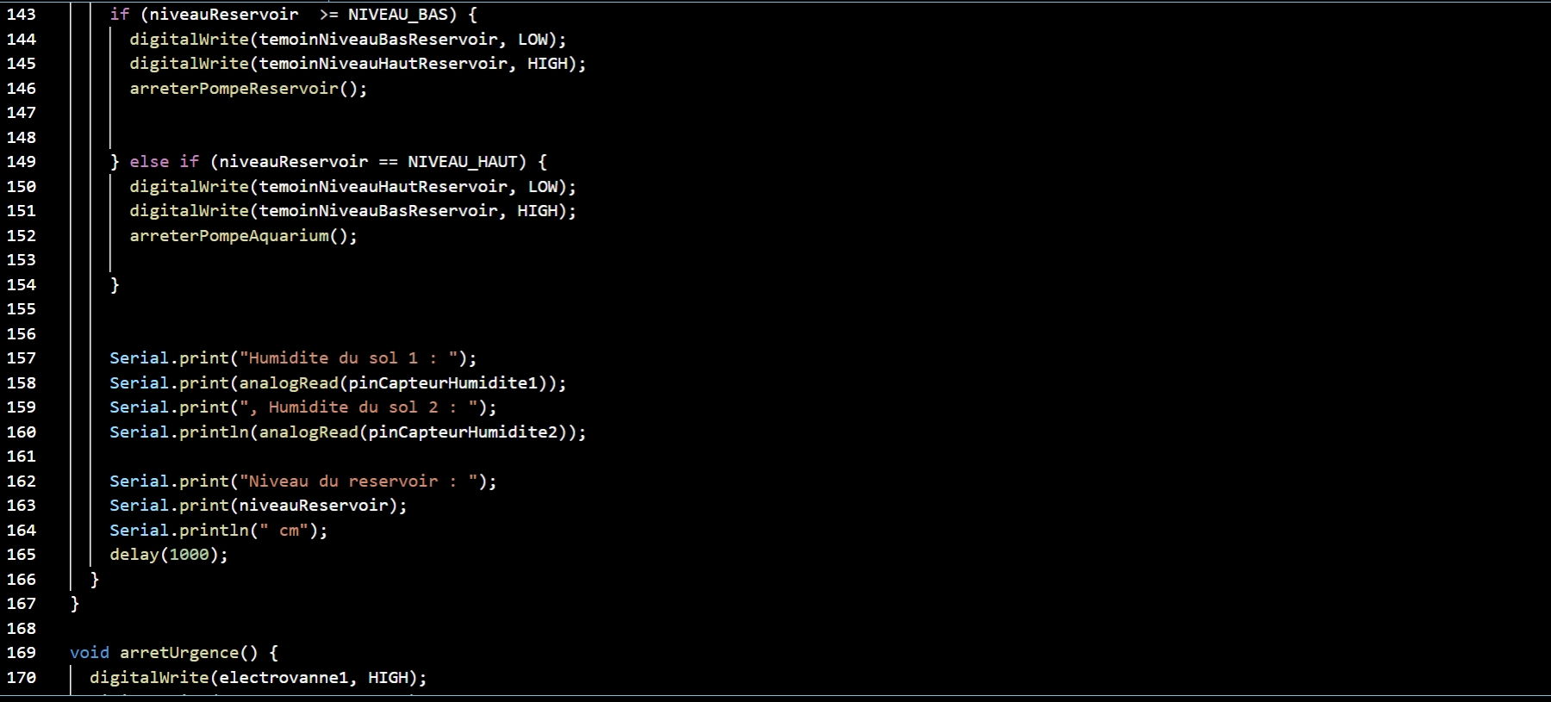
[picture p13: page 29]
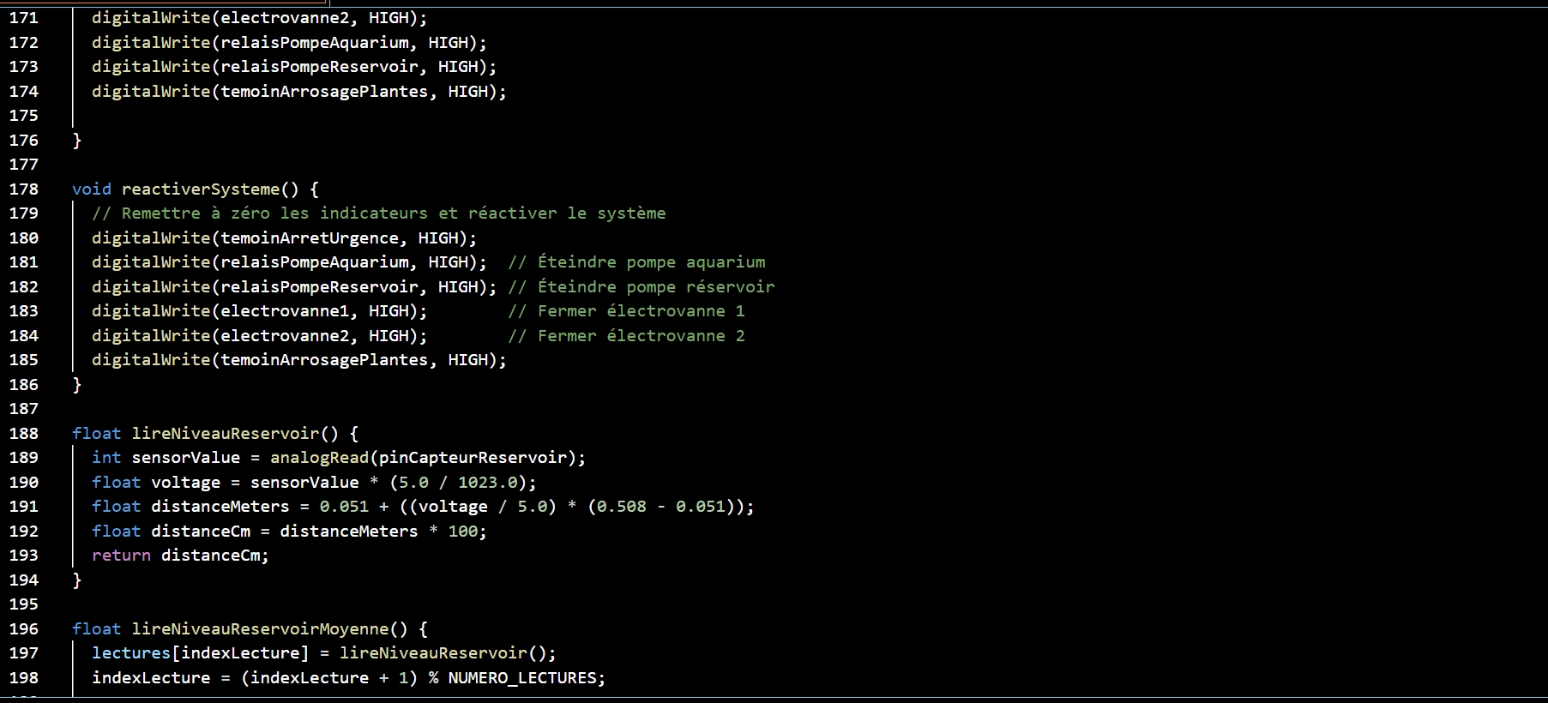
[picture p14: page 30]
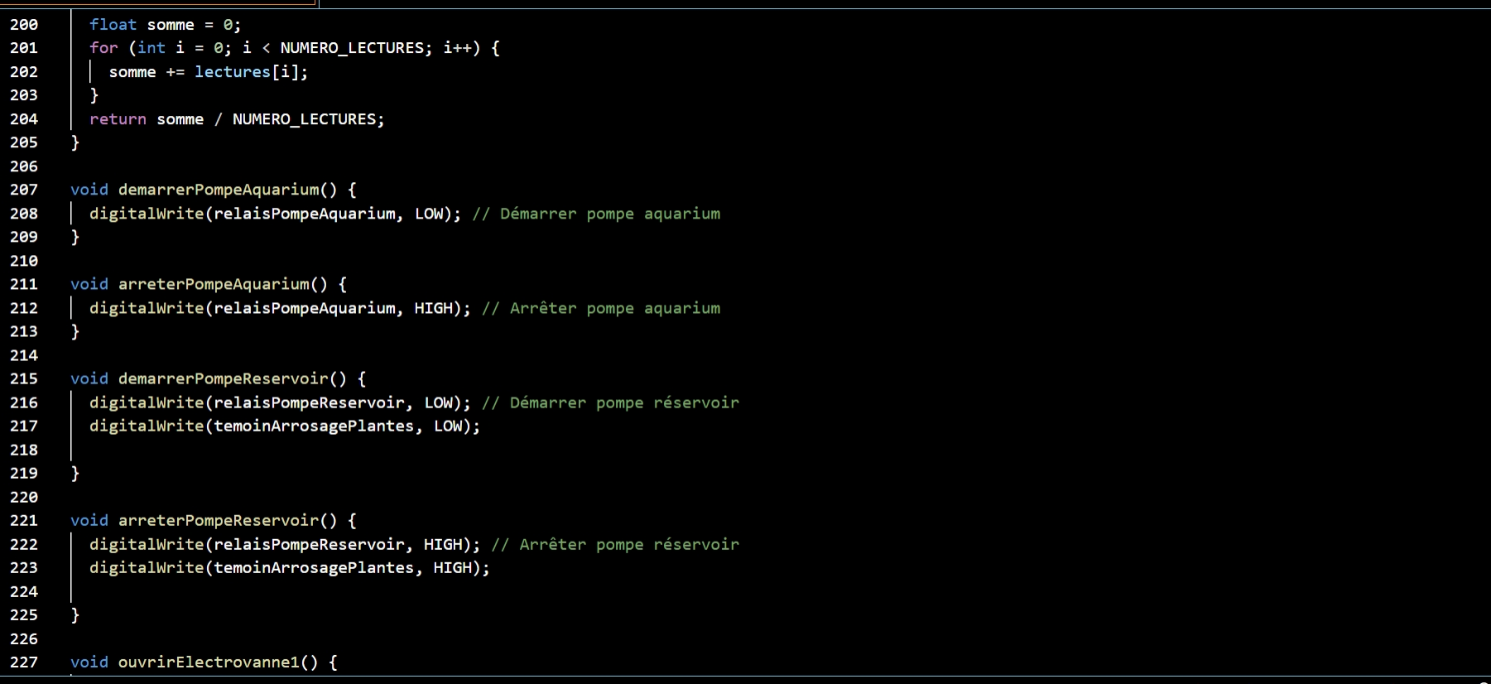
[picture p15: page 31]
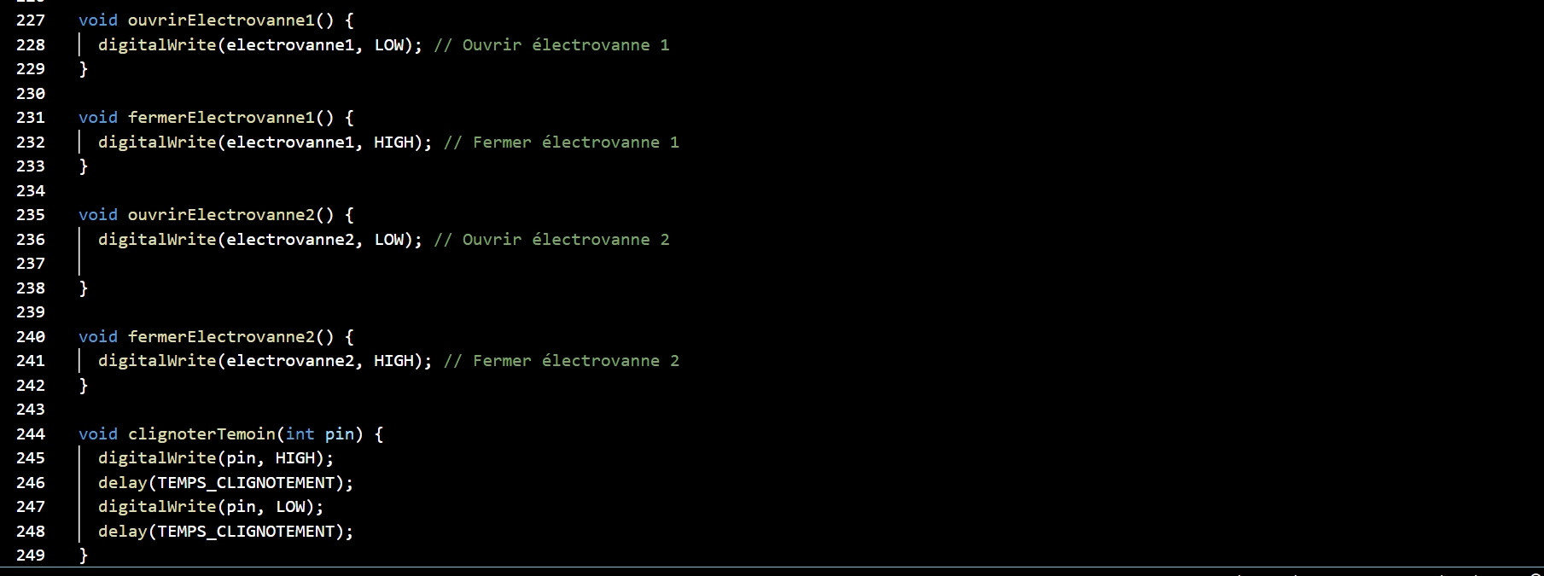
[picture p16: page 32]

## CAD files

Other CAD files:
schémas/schema_puissance.dwg
schémas/schema_commande.dwg

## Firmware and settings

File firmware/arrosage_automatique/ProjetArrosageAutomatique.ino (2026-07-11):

const int pinCapteurReservoir = A1; // Capteur ultrason du réservoir
const int pinCapteurHumidite1 = A2; // Capteur d'humidité du sol 1
const int pinCapteurHumidite2 = A3; // Capteur d'humidité du sol 2

const int boutonArretUrgence = 2; // Bouton pour l'arrêt d'urgence
const int boutonManuel = 3; // Bouton pour le mode manuel
const int boutonRemplissage = 4; // Bouton pour le remplissage de la cuve externe
const int boutonResetArretUrgence = 5; // Bouton pour réinitialiser l'arrêt d'urgence
const int temoinArrosagePlantes = 6; // Témoin pour indiquer l'arrosage des plantes
const int temoinNiveauBasReservoir = 7; // Témoin pour indiquer un niveau bas d'eau dans le réservoir
const int temoinNiveauHautReservoir = 8; // Témoin pour indiquer un niveau haut d'eau dans le réservoir
const int temoinArretUrgence = 9; // Témoin pour indiquer l'arrêt d'urgence
const int relaisPompeAquarium = 10; // Relais pour la pompe de l'aquarium
const int relaisPompeReservoir = 11; // Relais pour la pompe du réservoir
const int electrovanne1 = 12; // Électrovanne pour le capteur d'humidité 1
const int electrovanne2 = 13; // Électrovanne pour le capteur d'humidité 2
const int selecteurModeManuel = A5; // Sélecteur pour le mode manuel
const int selecteurModeAutomatique = A4; // Sélecteur pour le mode automatique

const int TEMPS_CLIGNOTEMENT = 500; // Durée du clignotement en millisecondes

const int seuilHumidite1 = 500; // Seuil pour le premier capteur d'humidité
const int seuilHumidite2 = 500; // Seuil pour le deuxième capteur d'humidité

const float NIVEAU_HAUT = 6.0; // Niveau maximum dans le réservoir
const float NIVEAU_BAS = 50.0; // Niveau minimum dans le réservoir

const int NUMERO_LECTURES = 10; // Nombre de lectures pour la moyenne

float lectures[NUMERO_LECTURES];
int indexLecture = 0;

void setup() {
  pinMode(pinCapteurHumidite1, INPUT);
  pinMode(pinCapteurHumidite2, INPUT);
  pinMode(pinCapteurReservoir, INPUT);
  pinMode(boutonArretUrgence, INPUT_PULLUP);
  pinMode(boutonManuel, INPUT_PULLUP);
  pinMode(boutonRemplissage, INPUT_PULLUP);
  pinMode(boutonResetArretUrgence, INPUT_PULLUP);
  pinMode(temoinArrosagePlantes, OUTPUT);
  pinMode(temoinNiveauBasReservoir, OUTPUT);
  pinMode(temoinNiveauHautReservoir, OUTPUT);
  pinMode(temoinArretUrgence, OUTPUT);
  pinMode(relaisPompeAquarium, OUTPUT);
  pinMode(relaisPompeReservoir, OUTPUT);
  pinMode(electrovanne1, OUTPUT);
  pinMode(electrovanne2, OUTPUT);
  pinMode(selecteurModeManuel, INPUT_PULLUP);
  pinMode(selecteurModeAutomatique, INPUT_PULLUP);

  digitalWrite(relaisPompeAquarium, HIGH);  
  digitalWrite(relaisPompeReservoir, HIGH); 
  digitalWrite(electrovanne1, HIGH);        
  digitalWrite(electrovanne2, HIGH);        
  digitalWrite(temoinArrosagePlantes, HIGH); 
  digitalWrite(temoinNiveauBasReservoir, HIGH);
  digitalWrite(temoinNiveauHautReservoir, HIGH);
  digitalWrite(temoinArretUrgence, HIGH);

  // Initialiser les lectures à zéro
  for (int i = 0; i < NUMERO_LECTURES; i++) {
    lectures[i] = 0;
  }

  Serial.begin(9600);
}

void loop() {
  int etatBoutonArretUrgence = digitalRead(boutonArretUrgence);
  int etatBoutonResetArretUrgence = digitalRead(boutonResetArretUrgence);
  int etatBoutonManuel = digitalRead(boutonManuel);
  int etatSelecteurModeManuel = digitalRead(selecteurModeManuel);
  int etatBoutonRemplissage = digitalRead(boutonRemplissage);
  int etatSelecteurModeAutomatique = digitalRead(selecteurModeAutomatique);

  if (etatBoutonArretUrgence == HIGH) {
    arretUrgence();
    clignoterTemoin(temoinArretUrgence);
  } else {
        
    if (etatBoutonResetArretUrgence == LOW) {
      reactiverSysteme();
    }

     if (etatSelecteurModeManuel == HIGH && etatBoutonManuel == LOW) {

      demarrerPompeReservoir(); 
      ouvrirElectrovanne1();
      ouvrirElectrovanne2();
     

      } else {       
      while (lireNiveauReservoirMoyenne()  >= NIVEAU_BAS) {
       
      }   
      
      arreterPompeReservoir();
      fermerElectrovanne1();
      fermerElectrovanne2();

      }
      if (etatSelecteurModeManuel == HIGH && etatBoutonRemplissage == LOW) {
     demarrerPompeAquarium();
    } else {  
      while (lireNiveauReservoirMoyenne() == NIVEAU_HAUT) {
       // Attendre que le niveau atteigne le niveau haut
      }   
     arreterPompeAquarium();
     arreterPompeReservoir();
     fermerElectrovanne1();
     fermerElectrovanne2();


     }


    if (etatSelecteurModeAutomatique == HIGH) {
      int humidite1 = analogRead(pinCapteurHumidite1);
      int humidite2 = analogRead(pinCapteurHumidite2);

      if (humidite1 < seuilHumidite1 && humidite2 < seuilHumidite2) { // Les deux sols doivent être secs pour arroser

        ouvrirElectrovanne1();
        ouvrirElectrovanne2();
        demarrerPompeReservoir();

      } else {
        while (lireNiveauReservoirMoyenne()  >= NIVEAU_BAS) {
    
        // Attendre que le niveau atteigne le niveau bas
      }
        fermerElectrovanne1();
        fermerElectrovanne2();
        arreterPompeReservoir();

      }

    }

    float niveauReservoir = lireNiveauReservoirMoyenne();

    if (niveauReservoir  >= NIVEAU_BAS) {
      digitalWrite(temoinNiveauBasReservoir, LOW);
      digitalWrite(temoinNiveauHautReservoir, HIGH);
      arreterPompeReservoir();
      

    } else if (niveauReservoir == NIVEAU_HAUT) {
      digitalWrite(temoinNiveauHautReservoir, LOW);
      digitalWrite(temoinNiveauBasReservoir, HIGH);
      arreterPompeAquarium();

    } 
  

    Serial.print("Humidite du sol 1 : ");
    Serial.print(analogRead(pinCapteurHumidite1));
    Serial.print(", Humidite du sol 2 : ");
    Serial.println(analogRead(pinCapteurHumidite2));

    Serial.print("Niveau du reservoir : ");
    Serial.print(niveauReservoir);
    Serial.println(" cm");
    delay(1000);
  }
}

void arretUrgence() {
  digitalWrite(electrovanne1, HIGH);
  digitalWrite(electrovanne2, HIGH);
  digitalWrite(relaisPompeAquarium, HIGH);
  digitalWrite(relaisPompeReservoir, HIGH);
  digitalWrite(temoinArrosagePlantes, HIGH);

}

void reactiverSysteme() {
  // Remettre à zéro les indicateurs et réactiver le système
  digitalWrite(temoinArretUrgence, HIGH);
  digitalWrite(relaisPompeAquarium, HIGH);  // Éteindre pompe aquarium
  digitalWrite(relaisPompeReservoir, HIGH); // Éteindre pompe réservoir
  digitalWrite(electrovanne1, HIGH);        // Fermer électrovanne 1
  digitalWrite(electrovanne2, HIGH);        // Fermer électrovanne 2
  digitalWrite(temoinArrosagePlantes, HIGH);
}

float lireNiveauReservoir() {
  int sensorValue = analogRead(pinCapteurReservoir);
  float voltage = sensorValue * (5.0 / 1023.0);
  float distanceMeters = 0.051 + ((voltage / 5.0) * (0.508 - 0.051));
  float distanceCm = distanceMeters * 100;
  return distanceCm;
}

float lireNiveauReservoirMoyenne() {
  lectures[indexLecture] = lireNiveauReservoir();
  indexLecture = (indexLecture + 1) % NUMERO_LECTURES;

  float somme = 0;
  for (int i = 0; i < NUMERO_LECTURES; i++) {
    somme += lectures[i];
  }
  return somme / NUMERO_LECTURES;
}

void demarrerPompeAquarium() {
  digitalWrite(relaisPompeAquarium, LOW); // Démarrer pompe aquarium
}

void arreterPompeAquarium() {
  digitalWrite(relaisPompeAquarium, HIGH); // Arrêter pompe aquarium
}

void demarrerPompeReservoir() {
  digitalWrite(relaisPompeReservoir, LOW); // Démarrer pompe réservoir
  digitalWrite(temoinArrosagePlantes, LOW);

}

void arreterPompeReservoir() {
  digitalWrite(relaisPompeReservoir, HIGH); // Arrêter pompe réservoir
  digitalWrite(temoinArrosagePlantes, HIGH);

}

void ouvrirElectrovanne1() {
  digitalWrite(electrovanne1, LOW); // Ouvrir électrovanne 1
}

void fermerElectrovanne1() {
  digitalWrite(electrovanne1, HIGH); // Fermer électrovanne 1
}

void ouvrirElectrovanne2() {
  digitalWrite(electrovanne2, LOW); // Ouvrir électrovanne 2

}

void fermerElectrovanne2() {
  digitalWrite(electrovanne2, HIGH); // Fermer électrovanne 2
}

void clignoterTemoin(int pin) {
  digitalWrite(pin, HIGH);
  delay(TEMPS_CLIGNOTEMENT);
  digitalWrite(pin, LOW);
  delay(TEMPS_CLIGNOTEMENT);
}

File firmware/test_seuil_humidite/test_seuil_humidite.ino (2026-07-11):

 
const int pinCapteurHumidite1 = A2; // Capteur d'humidité du sol 1
const int relaisPompeReservoir = 11; // Relais pour la pompe du réservoir
const int seuilHumidite1 =500; // Seuil pour le premier capteur d'humidité
const int electrovanne1 = 12; // Électrovanne pour le capteur d'humidité 1
void setup(){
   Serial.begin(9600);

   pinMode(pinCapteurHumidite1, INPUT);
   pinMode(electrovanne1, OUTPUT);
  pinMode(relaisPompeReservoir, OUTPUT);
}

void loop(){
   
  Serial.print(" : ");
  Serial.println(pinCapteurHumidite1);
  
   int humidite1 = analogRead(pinCapteurHumidite1);
   if (humidite1 < seuilHumidite1) {
    // Si l'humidité est inférieure au seuil, ouvrir l'électrovanne 1
    digitalWrite(electrovanne1, HIGH);
    digitalWrite(relaisPompeReservoir, HIGH);
  } else {
    // Sinon, fermer l'électrovanne 1
    digitalWrite(electrovanne1, LOW);
    digitalWrite(relaisPompeReservoir, LOW);
  }
 
  delay(1000); 

}

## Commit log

2026-07-11 Ajout du firmware Arduino : programme principal et test du capteur d'humidité
2026-07-11 Ajout des schémas commande et puissance (.dwg)
    [schema_commande.dwg, schema_puissance.dwg]
